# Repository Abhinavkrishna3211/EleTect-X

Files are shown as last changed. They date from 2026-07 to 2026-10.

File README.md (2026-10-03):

# EleTect X

**Adaptive Physical-AI platform for Human–Elephant Conflict (HEC) mitigation.**

EleTect X is a rugged, solar-powered, autonomous forest-edge node built on the Arduino UNO Q. It
detects elephants early through the ground (seismic), confirms with on-device vision, deters with
an adaptive, non-habituating light + sound response, alerts rangers and residents, and coordinates
with neighbouring nodes to steer wildlife safely — day and night, without cloud dependence in the
control loop.

## Why it's different

- **Seismic-primary, multimodal** detection (all-weather, day/night) — not a camera trap.
- **Adaptive deterrence** that measures outcomes and learns (contextual bandit), avoiding habituation.
- **Distributed coordination** — nodes create safe herding corridors, not random noise.
- **Ultra-low-power** event-driven architecture; weeks of autonomy on solar + LiFePO4.
- **Explainable fusion** — every alert traces back to which sensor said what, not a black box.
- **Extensible** — optional environmental / fire-risk / anti-poaching pods; road-signage integration.

## How it works

A node pairs an STM32U585 real-time microcontroller with a Qualcomm QRB2210 Linux computer on one
Arduino UNO Q board, split by responsibility rather than by chip:

```text
   Geophone / mic (always-on, µA)
            │
            ▼
   ┌────────────────────┐   footfall / acoustic events   ┌──────────────────────┐
   │  MCU — reflex       │ ───────────────────────────▶  │  MPU — cognition      │
   │  STM32U585          │  ◀───────────────────────────  │  QRB2210 (Linux)      │
   │  sensors, actuators,│      decisions (deter/alert)   │  vision, fusion,       │
   │  LoRa, power, safety│                                │  bandit, coordination  │
   └────────────────────┘                                └──────────────────────┘
            │                                                        │
            ▼                                                        ▼
   Horn + LED deterrence · IR illumination             LoRaWAN uplink → ranger dashboard
```

- **Reflex (MCU, always-on):** geophone STA/LTA trigger, acoustic gunshot/chainsaw gate, actuator
  timing, safety rule-gates, LoRa MAC, power management. Runs whether or not the MPU is awake.
- **Cognition (MPU, event-driven):** wakes on a reflex-layer event, runs an on-device vision
  detector, fuses every available sensor with a weighted log-odds model
  (`L = L_prior + Σ aᵢ wᵢ (ℓᵢ − ℓ₀ᵢ)`, explainable — missing sensors just drop out), then picks a
  deterrence action with a contextual bandit that never repeats the same tone and stops once the
  animal retreats, instead of blasting a fixed siren until it stops working. The 940 nm IR
  illuminator is deliberately outside that loop — it lights the scene so the camera can see after
  dark, and is invisible to the animal.
- **Coordination:** nodes share detections over LoRa so a herd is steered along a forest-side
  escape lane, not trapped toward a village.
- **Autonomy:** all control decisions are made on the node. The cloud side is monitoring and
  analytics for rangers and residents, never in the detect→deter loop.

## Repository layout

| Path | Contents |
| --- | --- |
| [`app-lab/`](app-lab/) | Arduino App Lab package (manifest + assets) — the deployable app |
| [`device/mcu/`](device/mcu/) | STM32U585 real-time reflex firmware (C/C++, PlatformIO) |
| [`device/mpu/`](device/mpu/) | QRB2210 (Debian) cognition: vision, fusion, bandit, comms (Python) |
| [`ml/`](ml/) | Seismic/acoustic/vision model training + evaluation (off-device) |
| [`hardware/`](hardware/) | PCB (KiCad), enclosure CAD, wiring, bill of materials |
| [`web/backend/`](web/backend/) | Supabase schema, row-level security, edge functions |
| [`web/ingest/`](web/ingest/) | ChirpStack MQTT → Supabase bridge |
| [`web/chirpstack/`](web/chirpstack/) | LoRaWAN network server stack (Docker Compose) — gateway to database |
| [`web/frontend/`](web/frontend/) | Ranger/resident dashboard + public site (React PWA) |
| [`docs/decisions/`](docs/decisions/) | Architecture decision records — the "why" behind every non-trivial call |
| [`docs/research/`](docs/research/) | Background research (behavioral science, platform, competitors) |
| [`docs/runbooks/`](docs/runbooks/), [`docs/specs/`](docs/specs/) | Field procedures and hardware bring-up specs |
| [`deployment/`](deployment/) | Field install scripts and service units |
| `scripts/`, `tests/` | Cross-cutting utilities and tests |

Each top-level module also has its own README with the detail specific to it —
[`device/README.md`](device/README.md), [`web/README.md`](web/README.md),
[`ml/README.md`](ml/README.md), [`hardware/README.md`](hardware/README.md).

## Getting started

### Run the app on real hardware

The fastest path to a working node is [`app-lab/eletect-x/`](app-lab/eletect-x/) — a real Arduino
App Lab package. In short:

```bash
cp device/mcu/src/secrets.h.example device/mcu/src/secrets.h   # fill in your LoRaWAN credentials
BOARD_HOST=<your-board>.local scripts/sync-to-board.sh
```

then build/run the `eletect-x` app from App Lab or `arduino-app-cli`. See
[`app-lab/eletect-x/README.md`](app-lab/eletect-x/README.md) for the full sequence and
prerequisites.

### Build and test each piece independently

| Module | Command | Notes |
| --- | --- | --- |
| `device/mcu` | `pio run -e native` / `pio test -e native` | Host-only compile/test harness; never produces a flashable image ([details](device/mcu/README.md)) |
| `device/mpu` | `ruff check .` / `pytest -q` | Host-only lint/test; the real Bridge runtime only exists on the board ([details](device/mpu/README.md)) |
| `ml/` | see [`ml/README.md`](ml/README.md) | Training pipelines, run on a PC |
| `web/frontend` | `npm run dev` / `npm run build` | React PWA — dashboard + public site |
| `web/backend` | see [`web/backend/README.md`](web/backend/README.md) | Supabase schema + edge functions |
| `web/ingest` | `npm test` / `npm run build` | MQTT → Supabase bridge ([details](web/ingest/README.md)) |
| `web/chirpstack` | `docker compose up -d` | LoRaWAN network server; needs Docker ([details](web/chirpstack/README.md)) |

### Inspect the trained models

Both on-device models are public on Edge Impulse — impulse, DSP block, training data, and the test
results they were accepted on, exactly as they run on a node:

| Model | Project | What it does |
| --- | --- | --- |
| Acoustic — `ETX-A` | [studio.edgeimpulse.com/public/1110036/live](https://studio.edgeimpulse.com/public/1110036/live) | PANNs Cnn10 transfer over a custom log-mel DSP block; `ambient` / `chainsaw` / `elephant_call` / `gunshot`, 92.6% over a 605-clip held-out split |
| Vision — `ETX-V` | [studio.edgeimpulse.com/public/1097972/live](https://studio.edgeimpulse.com/public/1097972/live) | YOLO-Pro object detector, 160 px int8 — detects `Elephant`, `Boar` and `Fox`, trained against a fourth `Background` class of negatives; confirms a reflex-layer trigger before any deterrence fires |

The training and evaluation pipelines that produced them, the per-sample dataset manifests, and the
caveats worth reading before quoting either number are in [`ml/acoustic/`](ml/acoustic/) and
[`ml/vision/`](ml/vision/).

### Understand a design decision

Every non-trivial engineering call — why seismic over camera-only, why this horn, why this fusion
math — is recorded as an ADR in [`docs/decisions/`](docs/decisions/), numbered in the order they
were made. Start with
[`0001-physical-ai-sensing-and-fusion-architecture.md`](docs/decisions/0001-physical-ai-sensing-and-fusion-architecture.md)
for the core sensing/vision/fusion architecture.

## Status

**Field testing.** The build is complete — reflex firmware, cognition layers, the LoRaWAN path and
the web app — and nodes are deployed in two areas, running the full detect → confirm → deter loop on
real hardware at the forest edge. The uplink path is live end to end: node → gateway → ChirpStack →
bridge → Supabase → dashboard.

## License

MIT — see [`LICENSE`](LICENSE).

The deterrence audio on the device is third-party work under separate terms. Three of the
five tracks are CC-BY and require attribution wherever this is distributed; the credits are
in [`docs/AUDIO_CREDITS.md`](docs/AUDIO_CREDITS.md) and travel with any build or write-up
that ships the sounds.

The training corpora are third-party work too, and the MIT licence above does not cover them. The
vision set is CC BY 4.0 and CDLA-Permissive, which require attribution; per-source terms are in
[`ml/vision/dataset_manifest.json`](ml/vision/dataset_manifest.json) and the table in
[`ml/vision/README.md`](ml/vision/README.md). The acoustic set is mixed and is tracked per sample in
[`ml/acoustic/dataset_manifest.json`](ml/acoustic/dataset_manifest.json). Check both before reusing
the data; the models themselves carry no such restriction.

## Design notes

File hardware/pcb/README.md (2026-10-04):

# Schematics

`eletect_x/` is the KiCad project for the field board: four sheets (geophone, LED and IR, sound and
LoRa, power) under one root sheet, with the same Arduino UNO Q drawn on each. `eletect_x_schematics.pdf`
is the full export and `erc_report.txt` the last ERC run.

The sheets and the field board are the same design. There are no known differences to track.

Pins used on the UNO Q match `device/mcu/src/config.h`:

| Sheet | Pins |
|---|---|
| Geophone | A4/PC1 SDA, A5/PC0 SCL (I2C3, `Wire2`) |
| LED and IR | D3/PB0 left wing, D6/PB1 right wing, D7/PB2 IR board |
| Sound and LoRa | D0/PB7 RX, D1/PB6 TX, D4/PA12 select, D11/PB15 amp enable |

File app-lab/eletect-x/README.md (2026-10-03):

# EleTect-X — App Lab package

This folder is the deployable Arduino App Lab package for the real EleTect-X app —
the thing that actually runs on the UNO Q. It is **not** a copy of the source: the
MCU sketch lives in [`device/mcu/src/`](../../device/mcu/) and the MPU program lives
in [`device/mpu/`](../../device/mpu/); those two directories are the single source of
truth and have their own build/test tooling (PlatformIO, `ruff`/`pytest`). This folder
holds only what an App Lab app needs that isn't part of either source tree — the
manifest and any bundled assets — plus the one-command script that assembles the two
into a real app on your board.

## Layout

```text
app-lab/eletect-x/
  app.yaml     App Lab manifest (name, icon, ports, bricks)
  assets/      Static assets bundled with the app (currently empty)
  README.md    this file
```

At deploy time, `scripts/sync-to-board.sh` fills in the two directories App Lab
expects alongside `app.yaml` — `sketch/` from `device/mcu/src/` and `python/` from
`device/mpu/` — directly on the board. They are not created or committed here, so
there is exactly one place to edit MCU or MPU code, never two copies to keep in sync.

## Deploying — the fast path

1. Install [App Lab](https://docs.arduino.cc/software/app-lab/) and complete its
   First Setup wizard against your UNO Q at least once, so the board has Wi-Fi,
   SSH, and `arduino-app-cli` set up.
2. Copy `device/mcu/src/secrets.h.example` to `device/mcu/src/secrets.h` and fill in
   your own LoRaWAN OTAA credentials.
3. Put the vision checkpoint in place. Model binaries are not versioned in this
   repo, so `device/mpu/models/vision/` is empty in a fresh clone and the sync
   script aborts until you fill it. Export the deployed build —
   `runF_res160_noattnrelu_int8.eim`, YOLO-Pro 160 px int8 — from Edge Impulse
   project [1097972](https://studio.edgeimpulse.com/public/1097972/live) as a Linux
   (AARCH64) `.eim` and drop it there. [`ml/vision/README.md`](../../ml/vision/README.md)
   records the exact build and its `sha256` so you can confirm you have the right bytes.
4. From the repo root, with the board reachable over SSH:

   ```bash
   BOARD_HOST=<your-board>.local scripts/sync-to-board.sh
   ```

   This pushes `app.yaml` and `assets/` from this folder, the MCU sketch, the MPU
   program and the vision checkpoint into `~/ArduinoApps/eletect-x/` on the board,
   creating the app if it doesn't exist yet.
5. Install the vision runner, once per board:

   ```bash
   BOARD_HOST=<your-board>.local deployment/install/install-vision-runner.sh
   ```

   The Edge Impulse runner has to run host-side as the `arduino` user rather than
   inside the App Lab container — the container is on a bridge network and cannot
   reach the host's `127.0.0.1:1337`. The unit this installs loads the checkpoint
   synced in step 4 and serves inference on port 1337; the MPU program is a client
   of it.
6. Open App Lab (or `arduino-app-cli`) and build/run the `eletect-x` app like any
   other App Lab project.

See [`device/mcu/README.md`](../../device/mcu/README.md) and
[`device/mpu/README.md`](../../device/mpu/README.md) for what each side actually
does, and the root [`README.md`](../../README.md) for the full project layout.

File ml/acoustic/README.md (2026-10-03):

# Acoustic classifier — four-class model, trained on real public + field-captured data

> **Looking for the walkthrough?** [`TUTORIAL.md`](TUTORIAL.md) is the step-by-step version —
> empty Edge Impulse project through to a model registered on the board, written for someone
> reproducing this from scratch. This file is the working record: what was tried, what was
> measured, and what was rejected. The tutorial is narrative; this is evidence.

## Which Edge Impulse project is production

**Production is project 1110036 (`ETX-A`), impulse 19, deploy v7** — the PANNs Cnn10 transfer
model. Enterprise account; project ID only is recorded here, the API key is not in the repo and
must be supplied through `EI_API_KEY` at run time.

The history is worth stating once, because two projects appear all over this file and **their
names were swapped in Studio on 2026-10-03**: 1110036 was `ETX-Test` and is now `ETX-A`, while
1109511 was `ETX-A` and is now `ETX-A-test`. Text written before that date — here, in the ADRs and
in captured console output — still uses the old names. **Go by project ID, never by name.**

**1109511 (`ETX-A-test`; `ETX-A` before the rename)** was built on 2026-09-23 to *be* production: a clean rebuild from the frozen
group-aware split, deliberately kept off the experiment path so its history stayed clean. It did
not reach the bar. Its best MFE configuration missed the 80%-per-class target on every class, and
`chainsaw` sat in the high single digits to mid-twenties across six separate real training runs on
the identical post-audit dataset (four MFE, two MFCC) — see the 2026-09-22 and 2026-09-15 Result
sections below, and `ACOUSTIC_MODEL_REPORT.md` for why.

**1110036 (`ETX-A`; `ETX-Test` before the rename)** started as the scratch project for
architecture/data/DSP/window sweeps.
The PANNs Cnn10 transfer impulse built there cleared the bar that 1109511 never did:

| | 1110036 impulse 19 |
|---|---|
| overall, 605 held-out clips | **92.6%** |
| ambient | 92.8% recall / 92.8% precision |
| chainsaw | 91.2% recall / 89.9% precision |
| elephant_call | 93.1% recall / 91.5% precision |
| gunshot | 92.6% recall / 93.4% precision |

So the roles swapped: the scratch project carries the model that works, and it is what ships. See
[ADR 0032](../../docs/decisions/0032-acoustic-production-project-is-1110036.md).

**The comparison is like-for-like, not a leakage artefact.** That is the first thing to check when
a scratch project outscores a carefully-built one by thirty points, and it was checked. 1110036 was
re-uploaded from the same frozen split: all 4,293 clips pushed with label **and** train/test
category driven by `harness/split.json` rather than by Studio's own 80/20, verified by API as an
exact filename-and-label match (training 3,688 / testing 605, 0 missing, 0 extra), and re-verified
against `ei_upload_ledger.json` at scoring time (605/605). The 92.6% above is measured over the
same 605 test clips the harness uses, so it is directly comparable to every other number in this
file. Full numbers: `harness/results_eim_impulse19.json`.

**Naming hazard — fixed in Studio, but inverted in older text.** The 2026-10-03 rename removed the
original hazard: production (1110036) is now `ETX-A` and the dormant project (1109511) is
`ETX-A-test`. The remaining risk runs the other way. Anything written before that date calls
1110036 `ETX-Test` and 1109511 `ETX-A`, so a reader going by name could look at `ETX-A` in Studio,
believe the older docs when they call `ETX-A` the abandoned MFE project, and reset production.
Act on the project ID.

(An earlier project, 1094275, was abandoned before any of this work and is never referenced again
in this document or in either script.)

**Status: trained, with real held-out numbers.** The numbers in the Result sections below are
copied verbatim from `edge_impulse_train_acoustic.py`'s `report_results()` output for each run —
nothing in this document is estimated, rounded from a different run, or averaged across classes.

Most of those sections predate the PANNs model and describe 1109511's MFE/MFCC lineage. They are
kept because they are the evidence for why that lineage was abandoned, **not** because they
describe what ships. In particular, the 2026-09-22 "Result — MFE vs MFCC x `autoClassWeights` on
the current dataset" section is 1109511's final trained state (Run E), and each of its four runs
left 1109511's live impulse in whatever state that run produced — Run E was a deliberate rebuild
back to the best-known config so the project was not left worse. That is now history: 1109511 is
not the deployed model and its numbers must not be quoted as production.

## Class scheme, and why it is four classes, not seven

The wire scheme is:

```
gunshot, chainsaw, elephant_call, ambient
```

`elephant_call` is the only one of these that feeds the deterrence (bandit) fusion decision
in `device/mpu/services/reflex_loop.py`; the rest are alert/detection-only. See
`docs/decisions/0024-acoustic-species-classification-deferred.md` and its same-day amendment
for the routing decision this model plugs into (Track B, a separate deferred change — this
document covers only the model).

### `boar_call` and `predator_call` were sourced, trained, and dropped

The amendment that authorized this work originally scoped **seven** classes, adding
`boar_call` and `predator_call` (lion + leopard + tiger lumped) to the five above. Both were
actually sourced (Freesound multi-query pulls, ESC-50 "pig" for boar, xeno-canto `Panthera`
and BBC Sound Effects for predator) and trained through the complete exploration described
below — data rebalancing, an `autoClassWeights` on/off A/B, a DSP A/B, an EON Tuner wide
search, a transfer-learning attempt, and the full `{3,4,6,8,10}` s window-length sweep. In
every one of those configurations, both classes stayed at or near the seven-class chance
floor (1/7 = 14.3%):

| window | `boar_call` recall | `predator_call` recall |
|---|--:|--:|
| 3.0 s | 2.6% | 10.7% |
| 4.0 s | 0.0% | 0.0% |
| 6.0 s | not trained — fell below the 150-clip data floor at this window length | 0.0% (n=3, test set collapsed) |
| 8.0 s | 0.0% | 0.0% |
| 10.0 s | 5.3% | 0.0% |

The EON Tuner's own best trial scored `boar_call` 18.4% and `predator_call` 0.0% across a
70-trial-budget search that explored MFE/MFCC/spectrogram DSP crossed with conv1d/conv2d
architectures — the platform's own automated search did no better. `autoClassWeights: True`
did lift both above chance on one dataset configuration (`boar_call` to 18.4%,
`predator_call` to 28.6%), but only by costing the two highest-stakes classes real recall
(`elephant_call` −16.5 points, `gunshot` −10.5 points) — see the `autoClassWeights` section
below for the full trade-off.

Per the explicit, pre-agreed fallback ("if boar and predator are working
very low, drop it after all possible fixes are explored"), both classes are **dropped from
the wire scheme entirely** — not folded into `ambient`, since `ambient` means background/
silence, not a mislabeled animal call, and folding would corrupt that class's meaning. The
device-side `AcousticClass` enum change this implies is a separate, deferred Track B edit;
this document and the two acoustic scripts are the only places the drop is applied. Every
fetcher, query table, and floor-handling special case for these two classes has been removed
from `scripts/edge_impulse_upload_acoustic.py` and `scripts/edge_impulse_train_acoustic.py`
rather than left in as dead code.

`boar_call`'s weak showing tracks a genuine data ceiling, not a code gap: its 12-query
Freesound search (`"wild boar"`, `"boar grunt"`, `"wild pig squeal"`, ...) against a 600-clip
cap only ever found 157 unique clips, plus 40 from ESC-50's "pig" category — 197 total,
nowhere near the other classes' final counts. `predator_call` never cleared the 150-clip
floor at all in the final configuration. xeno-canto was a hoped-for supplement for both but
returned zero clips — its v2 API is retired and v3 requires an account key this project does
not hold (confirmed live, not assumed).

### `vehicle` was retrained with real field data, then dropped (2026-09-14)

`vehicle` was part of the wire scheme from the start of this document and had its own
Freesound data widened on 2026-09-13 alongside `chainsaw` (see "Reading these numbers
honestly" below, in the pre-drop Result section this document used to lead with). At that
point `vehicle` looked like a genuine success story — held-out recall had jumped from 27.7%
to 55.6% — while `chainsaw` improved only modestly and the writeup at the time already
flagged, in prose, that "these two classes' Freesound-sourced audio — both sustained
mechanical/engine drones — sit close together in MFE feature space at this window length."

On 2026-09-14, 15 new real `chainsaw` clips and 10 new real `elephant_call` clips (laptop/
phone recordings, not Freesound) were added and the model retrained. `chainsaw` held-out
recall did not just fail to improve — it **collapsed to 0.0% (0/79)**. The training job's own
validation-time confusion matrix (not just the held-out split, which could in principle have
been an unlucky test draw) showed the same collapse during training: `chainsaw` recall was
1.7% (1/60) at validation time, with 33 of 60 `chainsaw` validation clips predicted `vehicle`.
Seeing the identical failure in both the training-time validation split and the independent
held-out test split is what confirmed this was a genuine, systematic class-boundary collision
between `chainsaw` and `vehicle` — not noise from one bad split. The new real clips did not
create this weakness; they pushed an already-documented latent one (see the prose warning
above, written the day before) into outright collapse. The bulk of both classes' data was,
and remained, Freesound-sourced sustained-engine-drone audio; the ~25 new laptop/phone clips
were a small fraction of either class's total.

Given the field-build deadline driving this work, the decision was to **drop `vehicle`
from the wire scheme rather than continue diagnosing the collision** — not fold it into
`ambient`, for the same reason `boar_call`/`predator_call` were not folded into `ambient`
above (`ambient` means background/silence, not a mislabeled vehicle). Dropping `vehicle` and
retraining recovered `chainsaw` to **55.7% (44/79) — its best score in this project's
history** (see the current Result section below for the full four-class numbers). All 517
`vehicle`-labeled samples (415 training + 102 testing) were deleted from Edge Impulse project
1109511 via the Studio API; the raw audio itself stays cached under
`ml/datasets/acoustic/raw/` (gitignored), so `vehicle` can be re-uploaded from cache without
re-fetching if the class is ever revived with a plan to actually separate it from `chainsaw`
(a different DSP/window, or audio sourced from something other than Freesound engine-drone
recordings). As with the boar/predator drop, every fetcher, query table, and constant
specific to `vehicle` has been removed from `scripts/edge_impulse_upload_acoustic.py` rather
than left in as dead code; `scripts/edge_impulse_train_acoustic.py` needed no functional
change since it already reads expected classes from the manifest rather than hard-coding
them.

## Dataset — the frozen split, as uploaded to project 1109511

> The dataset described here is the corpus both projects are trained and scored on. The
> *project* named below is 1109511, because this section was written when 1109511 was the
> designated production project; the same 3,688/605 split was later re-uploaded to 1110036
> by filename, which is what makes the two projects comparable. See ADR 0032.

Manifest schema `eletect-x/acoustic-clip-manifest/3`, `ml/acoustic/dataset_manifest.json`
(committed; records source, license, and sha256 for every clip the manifest currently
tracks — see the test-bucket note below for a case where this undercounts what is actually
in the project). Real counts, from that manifest, **after the 2026-09-15 chainsaw
data-quality audit and ambient-cap pullback** (see the two subsections immediately below —
this supersedes the 2026-09-14 all-four-classes-widening counts quoted in an earlier revision
of this table; see git history if those are needed):

| Class | Total | Train | Test | Primary sources (license as recorded per clip) |
|---|--:|--:|--:|---|
| `gunshot` | 577 | 382 | 195 | Mendeley `x48cwz364j` v3 + Freesound 19-query supplement, mostly CC0/CC BY |
| `ambient` | 762 | 610 | 152 | Mendeley `x48cwz364j` v3 background folder + ESC-50 nature categories (crickets/insects/chirping_birds/wind/frog/rain, CC BY-NC 3.0) + Freesound 11-query forest/jungle-ambience supplement |
| `chainsaw` | 227 | 178 | 49 | ESC-50 ESC-10 subset (CC BY) + Freesound 19-query supplement (`"power saw"` dropped 2026-09-15 — see below), mostly CC0 |
| `elephant_call` | 382 | 303 | 79 | `github.com/HiruDewmi/Audio-Classification-for-Elephant-Sounds` (**no license** — see Caveats) + Freesound 18-query supplement, mostly CC0/CC BY |

This table reports `dataset_manifest.json`'s own per-class counts, which — per the
"manifest is a floor, not the real count" note below — undercount what the live project
actually holds: the training runs in the Result section below report **1,775 training / 552
testing** clips read from project 1109511 at train time, larger than this table's 1,341/475
sum for the same reason documented since the first time this gap was noticed (the resumable
upload ledger accumulates clips across every historical run's differently-seeded sample; the
manifest keeps only the latest run's own selection). Field-captured XIAO and laptop/phone
clips from earlier revisions of this table are still present in the raw cache and in earlier
uploaded batches and contribute to that live-project total even though they no longer appear
in the manifest's latest per-class breakdown above. `vehicle` (dropped 2026-09-14, see the
class-scheme section above) stays out of the wire scheme. Every class clears the project's
own data floor (`CLIP_FLOOR = 150`) and is tagged `floor_status: trained` in the manifest.

**Superseded as of 2026-09-23: the live project now holds 3,688 training / 605 testing
clips.** The 1,775/552 figures below are accurate for the runs that recorded them and are
left as written, but they are no longer the current size of project 1109511. Every number in
the 2026-09-23 investigation is on the 3,688/605 data, and the 605 testing clips are the
canonical held-out set that all comparisons are scored against.

### Chainsaw data-quality audit — the `"power saw"` query dropped (2026-09-15)

The 2026-09-14 all-four-classes widening's own writeup (see the Result section below it, and
Caveat 5) flagged the `"power saw"` Freesound query — which alone contributed 138 of
`chainsaw`'s 321 Freesound clips at the time — as the leading, but unverified, suspect for
that widening's `chainsaw` collapse (55.7%→18.8%/13.9%). That audit was carried out: all 136
clips the query pulled were listened to. The finding is not what was guessed — the query does
not mostly return other power tools (circular saws, angle grinders); it mostly returns two
kinds of genuinely off-target audio that share the query term's ambiguity: synthesizer
"sawtooth waveform" demos (the tool/waveform sense of "saw") and generic factory/mechanical-
impact sound-effects-pack content, both cases where "power saw" over-matched Freesound's tag
search rather than the class label matching real chainsaw audio. `"power saw"` was removed
from `FREESOUND_QUERIES["chainsaw"]` and the remaining chainsaw query list widened from 13 to
19 real chainsaw-specific queries (`"chainsaw cutting wood"`, `"logging chainsaw"`, `"Stihl
chainsaw"`, `"Husqvarna chainsaw"`, `"motosierra"`, `"tronconneuse"`, and others) to replace
the lost volume with on-target audio instead. This is a genuine, verified data-quality fix,
not a guess carried forward unverified — see the Result section below for whether it actually
recovered `chainsaw`'s recall (it did not, cleanly — read that section before assuming this
fix worked).

### Ambient-cap pullback (2026-09-15)

The same all-four-classes widening grew `ambient` to 700 total clips specifically to test
whether more ambient volume would help (it did, but only under `autoClassWeights: False` —
see that Result section's honest read). Separately, `AMBIENT_CAP` had briefly been pushed
further, to 700 within the upload script's own per-run cap (not merely the manifest's `700`
row above), which combined with the ESC-50 nature supplement and the XIAO field clips to push
`ambient`'s live TRAIN split to roughly 750 — about 5x the thinnest trained class — at which
point, with `autoClassWeights` off, the model answered `ambient` for nearly every clip
regardless of true label. `AMBIENT_CAP` was pulled back to 200 (keeping the ESC-50 nature
supplement — genuinely different recording rigs — in full, cutting only the redundant
single-rig Mendeley share) so `ambient`'s volume advantage stays within roughly 2x the
trained species classes rather than 5x. A large negative class is still deliberately kept
as the main defence against a false-positive storm in the field; it just cannot be allowed to
dominate the softmax outright.

### `elephant_call` Freesound query widened 3→12, then retrained (2026-09-14)

After the `vehicle` drop retrain (below) showed `elephant_call` as the model's weakest class
at 37.0% held-out recall, `FREESOUND_QUERIES["elephant_call"]` in
`scripts/edge_impulse_upload_acoustic.py` was widened from 3 queries to 12 ("elephant rumble",
"elephant trumpet", "elephant call", "elephant roar", "elephant bellow", "elephant
vocalization", "elephant growl", "elephant scream", "wild elephant sound", "elephant herd",
"baby elephant", "elephant infrasound"). Real yield, per query, from a live Freesound search:
"elephant trumpet" (28 hits), "elephant roar" (11), "elephant growl" (9), "elephant scream"
(9), "elephant call" (6), "elephant rumble" (2), "elephant vocalization" (2), "wild elephant
sound" (3), "elephant bellow" (1); "elephant herd", "baby elephant", and "elephant infrasound"
returned 0 hits each. After deduping against the clips the original 3-query pull had already
found, this added **16 net-new clips** (49 unique Freesound clips total vs. 33 before) —
`elephant_call`'s total went from 394 to 410 (313→326 train, 81→84 test). xeno-canto still
contributes 0 clips (`gen:Elephas`, API v3 needs an account key that is not set). The retrain
against this larger pool did raise `elephant_call`'s held-out recall substantially (see the
Result section below), but total model accuracy barely moved and the gain traces mostly to
`ambient` and `chainsaw` losing votes to `elephant_call` rather than to a cleaner decision
boundary — read that section's honesty subsection before treating this as a fix.

### Why the manifest's per-class test count is a floor, not the real count

Because the resumable `uploaded.json` ledger only *adds* newly-selected clips and never
removes one a later run's reseeded sample no longer includes, a class's real EI-side train/
test bucket is the union of every historical run's selection, while the manifest only records
the *latest* run's sample. This has shown up repeatedly across this project's history at
varying scale — a 14-training/1-testing-clip gap before the 2026-09-13 chainsaw/vehicle
widening, a 10/32-clip gap for chainsaw/vehicle after it, a 1,487/476-vs-1,341/436 gap after
the 2026-09-14 `elephant_call` widening — and shows up again, largest yet, after the
2026-09-15 chainsaw audit and ambient-cap pullback: every training run in the current final
Result section below reports Edge Impulse reading **1,775 training / 552 testing** clips from
project 1109511, versus this section's own 1,341/475 manifest sum — a 434/117-clip gap. The
manifest's per-class counts are real and verified (they are exactly what the most recent
upload run selected and recorded), they simply undercount what the live project actually holds
after several historical runs' worth of accumulated clips. The Result sections below report
each `classify` job's own real per-class counts (which do match that run's own training-log
testing total), not the manifest's, since that is what the model was actually tested against.

### Normalization (all sources)

- **8000 Hz mono** — matches the INMP441 target rate and Mendeley's native rate (the lowest
  of all sources), so every other source is downsampled, never upsampled. Resampling uses
  `scipy.signal.resample_poly` (anti-aliased), not stdlib `audioop.ratecv` — `ratecv` has no
  real anti-alias filter, and decimating 44.1 kHz Freesound/ESC-50 audio at roughly 5.5:1
  without one folds high-frequency energy back down into exactly the low mel bands the MFE
  DSP block reads.
- **10.0 seconds per clip**, centre-cropped or zero-padded — the window-length sweep's
  winner; see that section below for why.
- XIAO ESP32S3 Sense field captures get an additional DC-offset removal step (the onboard
  PDM MEMS mic's raw output carries a DC bias that a plain resample does not fix).

## Impulse (locked configuration)

- **Input** (block 1): time-series, 1 axis, 8000 Hz, **10000 ms window, 10000 ms increase**
  (no overlap — one window per clip, so no window spans two clips or mixes a class label
  with padded-in silence from a shorter source clip).
- **DSP** (block 2): **MFE** (mel-filterbank energy), 40 filters / 256-point FFT — Edge
  Impulse's stock 8 kHz default, and separately measured against MFCC (see DSP A/B below).
  Frame length stays at the block default (0.02 s); frame stride is widened from the 0.01 s
  default to **0.020835 s** for this window length only, because Edge Impulse hard-caps
  feature generation at 500 frames per window and the 10 s window would otherwise compute
  ~499 frames (598 was measured to actually fail at 6 s) — `frame_stride_for_window()` in
  the training script widens the stride by the minimum amount needed, and only for windows
  that need it (3 s and 4 s keep the untouched 0.01 s default). This trades temporal
  resolution for headroom under the platform cap; it is a documented, deliberate
  trade-off, not a hidden one.
- **Learn** (block 3): Keras classification, from-scratch 2-layer 1D CNN —
  `conv1d(16) -> conv1d(32) -> dense(24)`, kernel size 3, 120 training cycles, learning rate
  0.001, batch size 32, **`autoClassWeights: False`**, spectrogram augmentation off,
  `minimumConfidenceRating: 0.1`, INT8 profiling on (`profileInt8: True`, matching the
  QRB2210 A53 Linux MPU deployment target).

  The block also carries `dropoutRate: 0.25/0.25/0.4`, and **that setting does nothing.**
  Dumping the Keras script Edge Impulse actually generates from this visual config shows no
  `Dropout` layer anywhere in it; the value is accepted by the API, echoed back on read, and
  never reaches the model. Confirmed by training two marker-verified expert-mode scripts that
  differ only in the presence of three `Dropout` layers. So every visual-mode run recorded
  below trained an unregularised network, whatever its stored config claims.

  **What the inert setting costs depends on the head, and is smaller than it first looked.**
  On Edge Impulse's internal validation slice the two scripts scored 61.25% / 0.579 macro F1
  without dropout and 63.96% / 0.616 with, which looked like a real +2.7. That slice is drawn
  from the training pool and is not group-aware, so it flatters regularisation; it is not a
  test set and should not be quoted as one. Re-scored on the canonical 605-clip test set,
  dropout on the stock `Flatten` head is worth +0.5 to +1.3 points — real, because Edge
  Impulse's training is deterministic and run-to-run variance is exactly zero, but minor.

  Once the head is replaced with global average pooling the sign reverses: 70.9% without
  dropout against 69.4% with. A 768-parameter head is already constrained enough that
  0.25/0.25/0.4 over-regularises it. The inert setting is a genuine Edge Impulse defect and it
  invalidated three experiment arms, but it was never the main cost — the `Flatten` head was.
  See [ACOUSTIC_MODEL_REPORT.md](ACOUSTIC_MODEL_REPORT.md) for the full accounting.

Every one of those choices was measured, not assumed — see Exploration history below.

## Exploration history (what was tried, what won, and why)

All of this ran against **1110036**, which was the scratch project at the time and is now
production (see "Which Edge Impulse project is production" at the top). So this history is the
deployed project's own history — the sweeps below are not a parallel track that was thrown away,
they are how the shipping model was arrived at. Every step is reproducible via the `--dsp`,
`--learn`, and `--clip-seconds` flags on `edge_impulse_train_acoustic.py`.

### Architecture search — closed, data-limited not capacity-limited

Three points were measured on the same (pre-final) dataset at a 4.0 s window:

| Architecture | Cycles | Held-out |
|---|--:|--:|
| 4-conv stack, dense-64 head, heavy spectrogram augmentation | — | ~26% argmax (near-random) — this was an earlier over-parameterized attempt that collapsed the majority class |
| 2-conv (16→32) + dense-24 | 120 | 46.4% (252/543) |
| 3-conv (24→48→64) + dense-32 | 250 | 45.2% (252/558) |

The larger net, wider head, and 2x training cycles bought nothing — the two curves sit on
top of each other and the train/held-out gap stayed ~4–5 points either way. That is a data
ceiling, not a capacity ceiling, so the smaller net was kept: identical accuracy, fewer INT8
parameters to profile and deploy. Architecture search closed here; every subsequent gain
came from the data, not the model.

### Data rebalancing — three iterations, real regressions along the way

Reported honestly because two of the three iterations were **regressions**, not just steps
toward the final config:

1. **Freesound gunshot supplement, no rebalancing** — added a 10-query Freesound pull for
   `gunshot` (Mendeley's own gunshot and ambient clips share one recording rig, so the model
   was keying on the rig's signature rather than the sound). Held-out total fell to 43.5%
   (269/618) — `gunshot` recall improved (+7 points) but `boar_call` and `chainsaw` collapsed
   to 2.6% and 4.4% because the uncapped `ambient` (940 clips) and `gunshot` (830 clips)
   swamped the thinner classes.
2. **Rebalance + XIAO field data folded in** (`GUNSHOT_TRAIN_CAP` 380→200,
   `FREESOUND_CAP["gunshot"]` 300→130, `AMBIENT_CAP` 700→200) — held-out total 41.3%
   (217/525), still below the original 46.4% baseline, but `elephant_call` jumped to 63.3%
   (real XIAO elephant-noise data helping directly) and `chainsaw`/`gunshot`/`vehicle` all
   improved. `boar_call` (2.6%) and `predator_call` (3.6%) stayed collapsed — this triggered
   the `autoClassWeights` A/B below.
3. This rebalanced-plus-XIAO configuration (with `autoClassWeights` locked `False`, see
   next section) is what carried forward into the DSP A/B, EON Tuner, transfer-learning
   attempt, and window sweep.

### `autoClassWeights` — measured both ways, locked OFF

Same uploaded data, same DSP/architecture, retrain-only comparison:

| Class | Weights OFF | Weights ON | Delta |
|---|--:|--:|--:|
| `elephant_call` | 63.3% | 46.8% | −16.5 |
| `gunshot` | 55.8% | 45.3% | −10.5 |
| `chainsaw` | 29.4% | 25.5% | −3.9 |
| `vehicle` | 38.3% | 36.2% | −2.1 |
| `ambient` | 30.7% | 29.7% | −1.0 |
| `boar_call` | 2.6% | 18.4% | +15.8 |
| `predator_call` | 3.6% | 28.6% | +25.0 |
| Total (micro) | 41.3% | 37.0% | −4.3 |

Turning class weighting on does lift `boar_call`/`predator_call` above the seven-class
chance floor — a real signal — but at the cost of the two highest-priority classes in the
deployed product: `gunshot` (P1 anti-poaching alert) loses 10.5 points and `elephant_call`
(alert **and** the sole acoustic input to the deterrence fusion decision) loses 16.5 points.
Weighted by the same elephant_call/gunshot/chainsaw priority average used for every other
decision in this document: 49.5% (weights off) vs. 39.2% (weights on). **Locked:
`autoClassWeights: False`.**

### DSP A/B — MFE vs MFCC, MFE wins decisively

`--dsp {mfe,mfcc}` on the identical rebalanced+XIAO dataset:

| Class | MFCC recall | MFE recall (locked) |
|---|--:|--:|
| `ambient` | 88.1% | 30.7% |
| `boar_call` | 0.0% | 2.6% |
| `chainsaw` | 11.8% | 29.4% |
| `elephant_call` | 55.7% | 63.3% |
| `gunshot` | 5.5% | 55.8% |
| `predator_call` | 0.0% | 3.6% |
| `vehicle` | 0.0% | 38.3% |
| **Total** | 28.4% (149/525) | 41.3% (217/525) |

Tie-breaker (elephant_call/gunshot/chainsaw weighted average): **MFCC 24.3% vs. MFE
49.5%** — more than 2x worse. The confusion matrix shows why: 164 of 181 `gunshot` clips
were predicted `ambient` under MFCC, which is also why `ambient`'s own recall looks inflated
(88.1%) — MFCC's cepstral truncation throws away exactly the transient/broadband energy
that separates a gunshot's percussive burst from background noise, which MFE's full
mel-band energy profile retains. This is expected: MFCC is a speech-tuned representation
(built to emphasize the smooth spectral-envelope shape that separates phonemes), applied
here to non-speech transient/impulsive sounds it was never designed for. **`--dsp` stays
defaulted to `mfe`.** Spectrogram was deliberately not added as a third variant — its
output bin count is not verified against the live API, and a wrong reshape-columns guess
risks a crash or silent misconfiguration for a block already expected to lose to MFE.

This comparison predates the chainsaw-audit/ambient-pullback dataset (project 1109511's current
1,775/552 4-class data) and was not re-verified against it until 2026-09-22 — see "Result — MFE
vs MFCC x `autoClassWeights` on the current dataset" below, which reconfirms the same verdict.

### EON Tuner — wide search, did not beat the hand-tuned config

Ran Edge Impulse's EON Tuner via its Enterprise API (`searchSpaceTemplate: audio_event`,
`targetDevice: arduino-unoq`, up to 70 trials across MFE/MFCC/spectrogram DSP crossed with
conv1d/conv2d architectures, INT8 optimization, 500 ms target latency). The search stopped
after 16 trials (the platform's own optimizer decided that was enough before entering full
optimization rounds). Best trial (`mfe-conv1d-934`): priority average 33.5%
(gunshot 52.5%, chainsaw 0.0%, vehicle 0.0%, elephant_call 48.1%, boar_call 18.4%,
predator_call 0.0%, ambient 8.9%) — well below the locked hand-tuned net's 49.5%. `chainsaw`
and `predator_call` scored exactly 0% in nearly every trial across the whole search space.
**Verdict: nothing to reproduce by hand — the locked from-scratch 2-conv net beat Edge
Impulse's own automated search.**

### EON Tuner — re-run on the current 4-class scheme (2026-09-15), still did not beat hand-tuning

The EON Tuner search above predates the `vehicle`/`boar_call`/`predator_call` drops and the
chainsaw data-quality audit, so it was re-run against project 1109511's current 4-class,
post-audit dataset (job `53782394`, `searchSpaceTemplate: audio_event`, `targetDevice:
arduino-unoq`) to check whether the narrower class scheme changed the conclusion. The search
ran 69.7 minutes and completed 10 trials, 5 of which returned metrics before the run stopped
itself. Best completed trial: int8 accuracy 56.52% (312/552 total), with `ambient` 52.6%,
`chainsaw` 2.1%, `elephant_call` 57.9%, `gunshot` 67.8%. This total is close to the range the
hand-tuned config's own runs land in (see the Result section below), but **the tuner's
`chainsaw` recall (2.1%) is far worse than any hand-tuned run achieves** — because, as
established in the earlier EON Tuner section above, **the tuner's search space varies only
the DSP block and the Keras architecture; it never varies `autoClassWeights`**, and every
trial in this run landed on the weights-off configuration this project already knows collapses
`chainsaw`. No trial was promoted with `set-tuner-primary-job` — nothing the tuner found beat
the manually-tuned, weights-on config on the metric this project actually cares about
(per-class recall on the minority classes, not total accuracy). **Verdict unchanged from the
7-class-era run: the tuner is not a substitute for hand-tuning `autoClassWeights` on this
dataset.**

### Transfer learning (`keras-transfer-kws`) — ruled out on a hard platform constraint

Attempted an A/B against all three confirmed-live pretrained KWS backbones
(`transfer_kws_mobilenetv1_a1_d100`, `transfer_kws_mobilenetv2_a35_d100`,
`transfer_kws_conv2d_tiny`; Syntiant NDP10x excluded — no hardware target for it). Every arm
was rejected identically: *"transfer learning for keyword spotting currently only works
with a window size of 1000ms"* — a hard, block-level Edge Impulse platform constraint, not
a per-backbone result. This project's window is far above 1000 ms because several classes
(a sustained chainsaw/engine whine, an elephant call, a running vehicle) need more than one
second of context to identify — they are not single-word "keyword" utterances the way KWS
transfer models assume. Forcing a 1 s window just to satisfy this block would have confounded
the comparison with an unrelated window-length change (1 s was never a window-sweep
candidate). **Not worked around — ruled out.** `TRANSFER_REQUIRED_WINDOW_MS` in the training
script fails this path fast, before wasting a feature-generation job, if anyone tries it
again at an incompatible window.

### Window-length sweep — all five candidates, no averaging

`{3.0, 4.0, 6.0, 8.0, 10.0}` seconds, each a full wipe → upload → train cycle against scratch
1110036 on the locked rebalanced+XIAO data, MFE DSP, `autoClassWeights` off, 2-conv net.
Picked by the elephant_call/gunshot/chainsaw priority average (the three highest-stakes
classes), never by raw total accuracy, since sample counts are not comparable across
candidates (re-cropping at a different window length changes how many non-overlapping
windows fit inside each raw source clip, so a class's real test-set size shifts with the
window — this is reported as observed below, not smoothed over).

| Window | Total good/bad | `ambient` | `boar_call` | `chainsaw` | `elephant_call` | `gunshot` | `predator_call` | `vehicle` | priority avg* |
|---|---|--:|--:|--:|--:|--:|--:|--:|--:|
| 3.0 s | 201/298 | 43.6% | 2.6% | 62.7% | 25.3% | 61.3% | 10.7% | 12.8% | **49.77%** |
| 4.0 s | 200/259 | 44.6% | 0.0% | 23.5% | 63.3% | 60.0% | 0.0% | 0.0% (n=7) | 48.93% |
| 6.0 s | 203/175 | 67.3% | not trained (below floor at this window) | 0.0% (n=14) | 55.6% | 52.5% | 0.0% (n=3) | 0.0% (n=7) | 36.03%† |
| 8.0 s | 233/292 | 46.5% | 0.0% | 39.2% | 39.2% | 67.4% | 0.0% | 27.7% | 48.60% |
| 10.0 s | 235/290 | 32.7% | 5.3% | 19.6% | 69.6% | 63.5% | 0.0% | 42.6% | **50.90%** |

\* elephant_call/gunshot/chainsaw simple average.
† 6.0 s excluded from serious contention: its `chainsaw` recall is measured on only 14 test
clips (vs. 51 at 3/4/8/10 s) and `boar_call` did not train at all at this window length —
longer windows mean fewer non-overlapping crops fit inside `boar_call`'s short raw source
clips, so the upload script's own data-floor logic pulled it below the training floor
entirely. This is a genuine, structural finding (window length and per-class data volume are
not independent), not an artifact of the frame-stride fix, but it makes 6.0 s unreliable to
compare against the other four.

**10.0 s wins** — highest priority average (50.90%) among the four reliable candidates, and
by a wide margin the best `elephant_call` recall (69.6%) of any window, which matters more
than raw total accuracy given `elephant_call`'s dual role (alert + fusion input). 3.0 s,
4.0 s, and 8.0 s all sit within about two points of each other and of 10.0 s on the priority
metric — this was not a landslide win, but it was the real winner by the metric this project
committed to before running the sweep. **Locked into `CLIP_SECONDS` (upload script) and
`DEFAULT_CLIP_SECONDS` (train script): 10.0 s.**

`boar_call` and `predator_call` recall across the five candidates
(3/4/6/8/10 s: boar 2.6%/0%/n·a/0%/5.3%, predator 10.7%/0%/0%/0%/0%) is the data referenced
in the class-scheme section above — at or near the chance floor in every reliable
configuration, which is what triggered the drop decision.

> **The Edge Impulse result sections below (every `## Result` heading dated 2026-09-22 or earlier)
> are superseded and their accuracies are withdrawn.** They were measured on a
> file-level split of a corpus of near-duplicates, which trained and tested on the same source
> recordings. They are kept as a record of what was tried and why, not as evidence of how well
> anything works. For held-out numbers, read
> *[Result — recording-level evaluation and an AudioSet-pretrained backbone](#result--recording-level-evaluation-and-an-audioset-pretrained-backbone-2026-09-23)*
> and the Caveats section, which explain the three leaks and quantify each one.

## Result — current production run (2026-09-14, 4-class, `vehicle` dropped)

This supersedes the 5-class result below. Same locked configuration (10.0 s window, MFE DSP,
2-conv architecture, `autoClassWeights: False`), run against project 1109511 after `vehicle`
was removed from the wire scheme and its samples deleted (see the class-scheme section
above), with the 15 new `chainsaw` and 10 new `elephant_call` laptop/phone clips already
folded in.

**Training job** (job 53749224, from Edge Impulse's own training-time validation split, 295
clips: ambient 77 / chainsaw 67 / elephant_call 63 / gunshot 88):

| Variant | Loss | Accuracy |
|---|--:|--:|
| float32 | 1.1112 | 51.2% |
| int8 | 1.2008 | 52.2% |

Training-time validation confusion matrix (float32; rows = true, columns = predicted, order
ambient/chainsaw/elephant_call/gunshot):

| True \ Predicted | `ambient` | `chainsaw` | `elephant_call` | `gunshot` |
|---|--:|--:|--:|--:|
| `ambient` | 33 | 22 | 5 | 17 |
| `chainsaw` | 16 | 36 | 8 | 7 |
| `elephant_call` | 9 | 19 | 29 | 6 |
| `gunshot` | 19 | 12 | 4 | 53 |

**Held-out model test** (job 53749250 — a real `classify` job over the actual test split, 473
clips, never seen during training; `minimumConfidenceRating: 0.1`, true argmax accuracy):

| Class | Good/Total | Recall | `floor_status` |
|---|--:|--:|---|
| `gunshot` | 148/212 | **69.8%** | trained |
| `chainsaw` | 44/79 | **55.7%** | trained |
| `ambient` | 44/101 | **43.6%** | trained |
| `elephant_call` | 30/81 | **37.0%** | trained |

**Total: 266/473 correct = 56.2%** (four-class chance floor = 25%).

**Confusion matrix** (rows = true label, columns = predicted; `uncertain` was 0 for every row
at `minimumConfidenceRating: 0.1`):

| True \ Predicted | `ambient` | `chainsaw` | `elephant_call` | `gunshot` |
|---|--:|--:|--:|--:|
| `ambient` | 44 | 29 | 4 | 24 |
| `chainsaw` | 17 | 44 | 7 | 11 |
| `elephant_call` | 24 | 24 | 30 | 3 |
| `gunshot` | 46 | 9 | 9 | 148 |

Full interactive results: <https://studio.edgeimpulse.com/studio/1109511/testing>

### Reading these numbers honestly

**`chainsaw` recovered to its best score in this project's history** (55.7%, up from 23.7% in
the last fully-documented 5-class run below, and up from 0.0% in the intervening run that
triggered the `vehicle` drop — see the class-scheme section above). Its confusion is now
spread across `ambient` (17/79) and `gunshot` (11/79) rather than concentrated in one
dominant confusable class, consistent with the vehicle-collision diagnosis: removing the one
class it was colliding with let its own decision boundary separate from the others again.

**`gunshot` improved too** (69.8%, above every gunshot number previously recorded for any
5-class configuration in this document, which ranged 55.8%–64.1%) and its confusion pattern
is unchanged in kind — still mostly `ambient` (46/212).

**`elephant_call` and `ambient` both regressed, and this is not yet fully explained.**
`ambient` fell to 43.6%, below every previously recorded 5-class number (55.4%–63.4%).
`elephant_call` fell to 37.0% (30/81) — below the 50.6% recorded for the 2026-09-13 widening
run, and further below the roughly 58.0% recall it scored in the run immediately preceding
the `vehicle` drop (training job 53748973 / classify job 53749012 — the same run whose
training-validation confusion matrix supplied the 33/60 chainsaw-to-vehicle misroute evidence
above). Its confusion is now split almost evenly between `chainsaw` (24/81) and `ambient`
(24/81). Two explanations are both consistent with what has been measured, and **no repeat
run was made to distinguish them**, given the build deadline:

1. **A genuine side effect of removing `vehicle`.** With `vehicle` gone, the softmax has one
   fewer place to route a misclassification — probability mass that a 5-class model might
   have (correctly or incorrectly) assigned to `vehicle` is now redistributed only among the
   remaining three off-target classes, and `chainsaw`/`ambient` may simply have picked up more
   of `elephant_call`'s spillover than `vehicle` used to.
2. **Ordinary run-to-run variance.** This project has already documented single-toggle swings
   of this general size — `autoClassWeights` alone moved `elephant_call` by 16.5 points and
   `vehicle` by up to 27.9 points in earlier A/Bs (see below) — so a ~13-21 point swing across
   a retrain that changed both the class roster *and* the training data is not unprecedented,
   even though it is on the larger end of what has been seen.

Total accuracy (56.2%) is reported for completeness only, per this document's standing
convention; it is not the metric this project optimizes for. The honest summary for this run
is: `chainsaw` is fixed, `gunshot` is fine, and `elephant_call` — the one class that also
feeds the deterrence fusion decision — is now this model's weakest point and the open
question for future work, not `chainsaw`.

## Result — retrain after widening `elephant_call` sourcing (2026-09-14, supersedes the run above)

Same locked configuration and class roster as the run above, retrained against project
1109511 after the Freesound query widening described in the Dataset section (+16 net-new
`elephant_call` clips, 394→410 total).

**Training job** (job 53749573, from Edge Impulse's own training-time validation split, 298
clips: ambient 77 / chainsaw 66 / elephant_call 69 / gunshot 86):

| Variant | Loss | Accuracy |
|---|--:|--:|
| float32 | 1.0383 | 54.7% |
| int8 | 1.0381 | 55.4% |

**Held-out model test** (job 53749601 — a real `classify` job over the actual test split, 476
clips, never seen during training; `minimumConfidenceRating: 0.1`, true argmax accuracy):

| Class | Good/Total | Recall | Prior run (394-clip `elephant_call`) | `floor_status` |
|---|--:|--:|--:|---|
| `gunshot` | 143/212 | **67.5%** | 69.8% | trained |
| `chainsaw` | 37/79 | **46.8%** | 55.7% | trained |
| `ambient` | 28/101 | **27.7%** | 43.6% | trained |
| `elephant_call` | 59/84 | **70.2%** | 37.0% | trained |

**Total: 267/476 correct = 56.1%** (four-class chance floor = 25%) — essentially unchanged
from the prior run's 56.2%.

**Confusion matrix** (rows = true label, columns = predicted; `uncertain` was 0 for every row):

| True \ Predicted | `ambient` | `chainsaw` | `elephant_call` | `gunshot` |
|---|--:|--:|--:|--:|
| `ambient` | 28 | 25 | 24 | 24 |
| `chainsaw` | 11 | 37 | 21 | 10 |
| `elephant_call` | 9 | 14 | 59 | 2 |
| `gunshot` | 44 | 8 | 17 | 143 |

Full interactive results: <https://studio.edgeimpulse.com/studio/1109511/testing>

### Reading these numbers honestly — this is not a clean win

`elephant_call` recall jumped 33.2 points (37.0%→70.2%), but **total accuracy barely moved**
(56.2%→56.1%), and the confusion matrix shows why this is not simply "more elephant data made
the model better": `ambient` collapsed by the same order of magnitude it gained (43.6%→27.7%),
and the votes `elephant_call` gained came substantially from `ambient` and `chainsaw` rather
than from resolving a genuine ambiguity. `ambient`→`elephant_call` misroutes rose from 4/101 to
24/101; `chainsaw`→`elephant_call` misroutes rose from 7/79 to 21/79; `chainsaw`'s own recall
fell in step (55.7%→46.8%). This reads as the three classes reshuffling which way their
confusion gets misrouted, not as the decision boundaries actually sharpening.

Sixteen additional clips (a 4% increase in `elephant_call`'s pool) is too small a change to
plausibly cause a swing this large through data volume alone. The far more likely explanation
is the same one flagged as unresolved after the `vehicle` drop above: this model's four
remaining classes have enough real overlap in the MFE feature space that which class "wins" a
given ambiguous clip is sensitive to small perturbations in training data and/or random
initialization — ordinary run-to-run variance, not a trend. **No repeat run was done to
separate signal from variance here either, given the build deadline.** Anyone using this
model's per-class numbers should treat a single run's `elephant_call`/`ambient`/`chainsaw`
figures as having roughly ±15-20 points of run-to-run noise until multiple repeated runs are
averaged (not blended into a single reported number — see this document's no-averaging rule —
but used to establish an honest confidence interval before the next real decision is made on
this model).

## Result — retrain after widening all four classes' sourcing (2026-09-14, supersedes the run above)

Following the `elephant_call`-only widening above, the Freesound query lists for **all four**
classes were widened (`gunshot` 10→15 queries, `chainsaw` 8→13, `elephant_call` 12→18, plus a
brand-new 12-query forest/jungle-ambience pull for `ambient`, which had none before), and the
per-class `FREESOUND_CAP` was raised (`gunshot`/`chainsaw` to 200/400, `ambient` capped at 260
for the new supplement). This was a direct response to the request to source more data and try
to reach 80% recall on every class. The resulting dataset (1,977 clips total — see the Dataset
table above) was uploaded to project 1109511 and retrained twice: once with this project's
long-standing `autoClassWeights: False` default, and once with it flipped on via the
`--class-weights` CLI override, to see whether `ambient`'s new 700-clip majority (it is now
larger than the other three classes combined) was distorting the un-weighted result.

**Project 1109511 data for both runs: 1,838 training / 587 testing clips.**

### Variant A — `autoClassWeights` off (the locked default)

**Training job** (job 53769500, Edge Impulse's own training-time validation split, 368 clips):

| Variant | Loss | Accuracy |
|---|--:|--:|
| float32 | 1.0822 | 57.1% |
| int8 | 1.0852 | 56.5% |

**Held-out model test** (job 53769558 — a real `classify` job over the actual 587-clip test
split, never seen during training; `minimumConfidenceRating: 0.1`, true argmax accuracy):

| Class | Good/Total | Recall | `floor_status` |
|---|--:|--:|---|
| `gunshot` | 165/249 | **66.3%** | trained |
| `chainsaw` | 19/101 | **18.8%** | trained |
| `elephant_call` | 30/84 | **35.7%** | trained |
| `ambient` | 106/153 | **69.3%** | trained |

**Total: 320/587 correct = 54.5%** (four-class chance floor = 25%).

**Confusion matrix** (rows = true label, columns = predicted; `uncertain` was 0 for every row):

| True \ Predicted | `ambient` | `chainsaw` | `elephant_call` | `gunshot` |
|---|--:|--:|--:|--:|
| `ambient` | 106 | 10 | 13 | 24 |
| `chainsaw` | 55 | 19 | 11 | 16 |
| `elephant_call` | 38 | 11 | 30 | 5 |
| `gunshot` | 72 | 3 | 9 | 165 |

### Variant B — `autoClassWeights` on (`--class-weights` override)

**Training job** (job 53769747, same 368-clip validation split):

| Variant | Loss | Accuracy |
|---|--:|--:|
| float32 | 1.1148 | 51.1% |
| int8 | 1.1139 | 52.2% |

**Held-out model test** (job 53769815, same 587-clip real test split):

| Class | Good/Total | Recall | `floor_status` |
|---|--:|--:|---|
| `gunshot` | 173/249 | **69.5%** | trained |
| `chainsaw` | 14/101 | **13.9%** | trained |
| `elephant_call` | 54/84 | **64.3%** | trained |
| `ambient` | 76/153 | **49.7%** | trained |

**Total: 317/587 correct = 54.0%.**

**Confusion matrix:**

| True \ Predicted | `ambient` | `chainsaw` | `elephant_call` | `gunshot` |
|---|--:|--:|--:|--:|
| `ambient` | 76 | 8 | 36 | 33 |
| `chainsaw` | 41 | 14 | 26 | 20 |
| `elephant_call` | 20 | 6 | 54 | 4 |
| `gunshot` | 53 | 4 | 19 | 173 |

Full interactive results: <https://studio.edgeimpulse.com/studio/1109511/testing>

### Reading these numbers honestly — 80% was not reached on any class, and this is a mixed result

Neither variant comes close to the 80%-per-class target. Total accuracy did not improve over
the prior `elephant_call`-only run (56.1% → 54.5% / 54.0%) despite nearly doubling the dataset
(1,251 → 1,977 clips). The two variants tell a clear, consistent story once read together
rather than in isolation:

- **`ambient` volume genuinely helped**, but only without class weighting. Growing `ambient`
  from 366 to 700 clips (now the largest class by a wide margin) pushed its own recall from
  27.7% to 69.3% under `autoClassWeights: False` — the biggest single-class swing seen in this
  project's history that is plausibly a real data effect rather than run-to-run noise, given the
  scale of the volume change. But `autoClassWeights: True` immediately gives most of that gain
  back (69.3%→49.7%), because reweighting explicitly discounts the now-dominant class in the
  loss function — confirming the gain is a volume/prior effect, not a sharper decision boundary.
- **Class weighting trades `ambient` for `gunshot` and `elephant_call`.** Turning weighting on
  recovers `elephant_call` from 35.7% to 64.3% and lifts `gunshot` from 66.3% to 69.5%, both by
  countering `ambient`'s now-oversized prior — consistent with how `autoClassWeights` is
  documented to work. This is the expected, mechanical effect of reweighting against a skewed
  class distribution, not a data-quality finding.
- **`chainsaw` is not fixed by weighting, and its confusion is not concentrated on the majority
  class.** `chainsaw` regressed in both variants (55.7% in the prior 5-class run → 18.8% off /
  13.9% on), and under weights-on its confusion matrix row spreads across all three other
  classes almost evenly (`ambient` 41, `elephant_call` 26, `gunshot` 20) rather than piling onto
  `ambient`, the way a pure imbalance artifact would. If `ambient`'s volume were the only cause,
  reweighting away from `ambient` should have recovered most of `chainsaw`'s recall the way it
  recovered `elephant_call`'s — it did not (13.9% is *worse* than the 18.8% weights-off number).
  This points to a genuine data-quality problem introduced by the widened `chainsaw` Freesound
  queries, not a class-imbalance artifact. The most likely single cause: the `"power saw"`
  query alone contributed 138 of `chainsaw`'s 321 Freesound-sourced clips (see the Dataset
  section above), and that query almost certainly pulls in non-chainsaw power-tool audio
  (circular saws, table saws, angle grinders) that shares spectral characteristics with a
  chainsaw's engine drone but is acoustically distinct enough to confuse the model rather than
  reinforce it. This has not been verified by manually auditing the "power saw" clips — that
  audit is flagged as follow-up work below, not done as part of this pass, to avoid further
  blind retrain cycles.

**No further retrain was attempted after Variant B.** Two real, honestly-reported configurations
already establish the shape of the tradeoff (ambient-volume gain vs. weighting-driven
redistribution vs. an unresolved chainsaw data-quality regression); continuing to try
hyperparameter combinations in search of a better number would drift toward exactly the kind of
fishing-for-a-good-run this document's no-averaging/no-fabrication convention exists to prevent.
Which of Variant A or Variant B is left as the live model in project 1109511 depends on which
failure mode is more acceptable operationally: Variant A (weights off) favors `ambient`/`gunshot`
at the cost of `elephant_call` and `chainsaw`; Variant B (weights on) favors `gunshot`/
`elephant_call` — the class that also feeds the deterrence fusion decision — at the cost of
`ambient` and a further-regressed `chainsaw`. Given that `elephant_call` is the one acoustic
class this model feeds into the bandit/deterrence decision (see the class-scheme section above),
**Variant B (`autoClassWeights: True`) was left as the trained state of project 1109511** after
here — this is a judgment call about which failure mode matters more for the deployment,
not a claim that Variant B is a better model in the aggregate; the total accuracy figures above
show it is not.

## Result — after the chainsaw data-quality audit and the ambient-cap pullback (2026-09-15, supersedes the run above)

Following the `"power saw"` audit and the `AMBIENT_CAP` pullback documented in the Dataset
section above, the dataset was re-uploaded to project 1109511 and retrained. **Project 1109511
data for every run below: 1,775 training / 552 testing clips**, MFE DSP, the locked impulse
(`--skip-impulse` reused the existing dsp/learn blocks for runs after the first). Four separate
real training runs were executed against this identical dataset — not two, as an earlier
internal note believed; the actual sequence, reconstructed from this project's own job history,
is reported below run by run, **with no averaging across runs and no cherry-picking the best
one as "the" result**.

### Run A — `autoClassWeights` on

Feature job `53779616` (5.5 min) → training job `53779914` (2.7 min) → held-out classify job
`53780104` (2.7 min).

| Class | Good/Total | Recall |
|---|--:|--:|
| `ambient` | 82/152 | **53.9%** |
| `chainsaw` | 12/48 | **25.0%** |
| `elephant_call` | 54/76 | **71.1%** |
| `gunshot` | 185/276 | **67.0%** |

**Total: 333/552 = 60.3%.**

### Run B — `autoClassWeights` off

Feature job `53780286` → training job `53780518` → held-out classify job `53780713` (2.7 min).

| Class | Good/Total | Recall |
|---|--:|--:|
| `ambient` | 117/152 | **77.0%** |
| `chainsaw` | 2/48 | **4.2%** |
| `elephant_call` | 29/76 | **38.2%** |
| `gunshot` | 167/276 | **60.5%** |

**Total: 315/552 = 57.1%.** This reconfirms the earlier weights-off finding: `ambient` recall
is the best of any run here, and `chainsaw` collapses almost to nothing (4.2%, worse than a
25% four-class chance floor's naive per-class baseline would suggest for a class this small).

### Run C — `autoClassWeights` on (repeat of Run A's exact configuration)

Feature job `53780862` → training job `53781206` → held-out classify job `53781440` (8.2 min).

| Class | Good/Total | Recall |
|---|--:|--:|
| `ambient` | 112/152 | **73.7%** |
| `chainsaw` | 9/48 | **18.8%** |
| `elephant_call` | 41/76 | **53.9%** |
| `gunshot` | 145/276 | **52.5%** |

**Total: 307/552 = 55.6%.**

*(Between Run C and Run D, the EON Tuner 4-class re-run above (job `53782394`) executed, and a
duplicate feature-generation job storm — jobs `53785901`/`53785905`/`53785906`, all finished
`successful=False` — had to be waited out and did not produce a usable result before Run D.)*

### Run D — `autoClassWeights` on (currently the live trained state of project 1109511)

Feature job `53785969` (5.1 min) → training job `53786057` (3.8 min) → held-out classify job
`53786113` (2.7 min).

| Class | Good/Total | Recall |
|---|--:|--:|
| `ambient` | 92/152 | **60.5%** |
| `chainsaw` | 9/48 | **18.8%** |
| `elephant_call` | 54/76 | **71.1%** |
| `gunshot` | 173/276 | **62.7%** |

**Total: 328/552 = 59.4%.**

Confusion matrix:

| True \ Predicted | `ambient` | `chainsaw` | `elephant_call` | `gunshot` |
|---|--:|--:|--:|--:|
| `ambient` | 92 | 6 | 28 | 26 |
| `chainsaw` | 23 | 9 | 13 | 3 |
| `elephant_call` | 15 | 4 | 54 | 3 |
| `gunshot` | 80 | 3 | 20 | 173 |

Full interactive results: <https://studio.edgeimpulse.com/studio/1109511/testing>

### Reading these numbers honestly — three identically-configured runs, one dataset, a wide spread

Runs A, C, and D all use the exact same `autoClassWeights: True` configuration against the
byte-identical 1,775/552 dataset, differing only in Edge Impulse's own training-run randomness
(weight initialization, minibatch order). Laid side by side, the spread is large enough that
**quoting any single one of these three runs as "the" chainsaw or ambient number would be
misleading**:

| | Run A | Run C | Run D | spread |
|---|--:|--:|--:|--:|
| `ambient` | 53.9% | 73.7% | 60.5% | **19.8 points** |
| `chainsaw` | 25.0% | 18.8% | 18.8% | 6.2 points |
| `elephant_call` | 71.1% | 53.9% | 71.1% | 17.2 points |
| `gunshot` | 67.0% | 52.5% | 62.7% | 14.5 points |
| total | 60.3% | 55.6% | 59.4% | 4.7 points |

This is a stronger, now-quantified version of the "±15-20 points of run-to-run noise" caveat
already carried in this document from the `elephant_call`-widening run — it is no longer an
estimate from two differently-configured runs, it is a measurement from three repeated runs on
one fixed dataset and one fixed configuration. Total accuracy is comparatively stable (55.6%–
60.3%, a 4.7-point spread); per-class recall is not, and `ambient` and `elephant_call` swing by
nearly 20 points each depending on nothing but which run you happen to look at.

`chainsaw` is the one class where this run-to-run noise does **not** rescue a hopeful reading:
its highest observed value across all four runs (A/B/C/D) and the EON Tuner's best trial is
25.0% (Run A), and its range (4.2%–25.0%) never approaches the 80% target from any angle tried.
The `"power saw"` audit's data-quality fix (see above) did not produce a clean recovery — Run D,
trained on the corrected dataset, still lands at 18.8%, statistically indistinguishable from
Run C's 18.8% on the pre-fix-adjacent dataset. Whatever is limiting `chainsaw` recall on this
device's fixed 8 kHz/10 s/MFE pipeline, it was not resolved by removing the one clearly
mislabeled query.

Run D used the same `autoClassWeights: True` judgment call documented in the prior Result section
(favoring `elephant_call`, the class that also feeds the deterrence fusion decision, over
`ambient`). It was not claimed to be the best of the four runs by any metric other than
recency — Run A's total (60.3%) and `chainsaw` recall (25.0%) were both marginally higher.
**Run D is no longer the live trained state of project 1109511** — see the MFE-vs-MFCC section
immediately below, whose final run (Run E) superseded it. **The honest conclusion, across every
configuration tried in this entire session — five hand-tuned MFE runs, the EON Tuner's automated
search, and two independent data-quality interventions — is that the 80%-per-class target was
not reached on any class, and `chainsaw` remains the persistent bottleneck, never exceeding 25%
recall under any real, verified condition.**

## Result — MFE vs MFCC x `autoClassWeights` on the current dataset (2026-09-22, supersedes Run D as the live state)

The DSP A/B section above (MFE vs MFCC) was measured on the older rebalanced+XIAO 7-class
dataset, not the current post-audit 1,775/552 4-class one — an earlier internal note believed a
comparison existed on the current dataset, but it did not until this run. All four runs below
share the identical 1,775/552 dataset; `--dsp mfcc` requires a full impulse rebuild (frame count
13 vs MFE's 40), so `--skip-impulse` was only used for the second run of each DSP-type pair.

### MFCC, `autoClassWeights` on

Feature job `54003784` (4.5 min) -> training job `54003892` (2.1 min) -> held-out classify job
`54003929` (2.4 min). (This exact configuration was run twice in immediate succession — an
earlier feature/train/classify triple, jobs `54003532`/`54003674`/`54003715`, produced numbers
identical to the digit, including training-time validation loss matching to 16 significant
figures. That is not plausible for two independently-initialized training runs and is most
likely Edge Impulse returning a cached/deduped result for the second invocation, consistent with
the duplicate-job behavior this project has seen before on this network. Only one data point is
counted here, not two.)

| Class | Good/Total | Recall |
|---|--:|--:|
| `ambient` | 107/152 | **70.4%** |
| `chainsaw` | 11/48 | **22.9%** |
| `elephant_call` | 42/76 | **55.3%** |
| `gunshot` | 146/276 | **52.9%** |

**Total: 306/552 = 55.4%.**

### MFCC, `autoClassWeights` off

Feature job `54013922` (0.3 min, reused MFCC impulse via `--skip-impulse`) -> training job
`54013926` (2.1 min) -> held-out classify job `54013978` (0.7 min).

| Class | Good/Total | Recall |
|---|--:|--:|
| `ambient` | 126/152 | **82.9%** |
| `chainsaw` | 2/48 | **4.2%** |
| `elephant_call` | 46/76 | **60.5%** |
| `gunshot` | 124/276 | **44.9%** |

**Total: 298/552 = 54.0%.**

### Run E — MFE, `autoClassWeights` on (rebuild; now the live trained state of project 1109511)

Feature job `54014006` (3.8 min) -> training job `54014102` (2.4 min) -> held-out classify job
`54014192` (2.1 min).

| Class | Good/Total | Recall |
|---|--:|--:|
| `ambient` | 90/152 | **59.2%** |
| `chainsaw` | 8/48 | **16.7%** |
| `elephant_call` | 54/76 | **71.1%** |
| `gunshot` | 168/276 | **60.9%** |

**Total: 320/552 = 58.0%.**

### The full grid, and why MFE stays the locked DSP block

| Config | `ambient` | `chainsaw` | `elephant_call` | `gunshot` | total |
|---|--:|--:|--:|--:|--:|
| MFE, weights on (Run D) | 60.5% | 18.8% | 71.1% | 62.7% | 59.4% |
| MFE, weights off (Run B) | 77.0% | 4.2% | 38.2% | 60.5% | 57.1% |
| MFCC, weights on | 70.4% | 22.9% | 55.3% | 52.9% | 55.4% |
| MFCC, weights off | 82.9% | 4.2% | 60.5% | 44.9% | 54.0% |
| MFE, weights on (Run E, live) | 59.2% | 16.7% | 71.1% | 60.9% | 58.0% |

MFCC's only advantage anywhere in this grid is `chainsaw`, and only against the weights-on MFE
runs (+4.1 points over Run D, +6.2 over Run E) — never against the weights-off MFE runs, where
MFCC and MFE tie at 4.2%. That small chainsaw gain costs `elephant_call` 15.8 points against
either weights-on MFE run (Run D and Run E tie at 71.1%), `gunshot` 8.0-9.8 points, and 2.6-4.0
points of total accuracy. Given `elephant_call`'s dual role (it also feeds the deterrence fusion
decision) and this project's stated priority — `elephant_call`/`gunshot`/`chainsaw` matter more
than raw total, but not in a way that justifies a 15.8-point `elephant_call` loss for a few
points of `chainsaw` — MFE remains the better DSP block, reconfirming the older DSP A/B
section's verdict on a dataset where it had never actually been tested. Project 1109511 was
rebuilt back onto MFE (Run E) so its live state reflects this conclusion rather than being left
on the worse MFCC config that happened to run last.

Run E's numbers track Run D's closely on `elephant_call` (71.1%, identical 54/76) and are within
a few points on `ambient`/`chainsaw`/`gunshot` — a fifth data point consistent with the
run-to-run-variance caveat below, not a contradiction of it.

## Result — historical: final 5-class run before the `vehicle` drop (superseded 2026-09-14)

This is the real, live run after the 2026-09-13 chainsaw/vehicle data widening: 5-class
scheme, 10.0 s window, the locked architecture and DSP above. Edge Impulse's own
training-run log reports **1,729 training / 536 testing** clips read for this job;
summing the per-class train/test counts in the Dataset table above gives 1,674 / 495
instead — a larger version of the same kind of discrepancy the pre-widening run already
had (there it was 14 training / 1 testing clip; see "Why the manifest's per-class test
count is a floor, not the real count" above for the now-identified mechanism — the ledger
accumulates clips across runs with different seeded samples, so the manifest's latest-run
counts undercount what is actually resident and being tested). The held-out numbers below
are Edge Impulse's own `classify` job output (536 real held-out clips, matching the
training log's testing count) and are internally consistent with each other; they are the
authoritative real-world test-set sizes, not the manifest's.

This run was reproduced twice with identical results (once as the direct widened-data
retrain, once again after repairing the manifest — see below), and a third variant with
`autoClassWeights: True` was also run as a genuine re-test (not previously tried on this
5-class roster) and discarded — see the addendum at the end of this section.

**Training job** (job 53728634, from Edge Impulse's own training-time validation split):

| Variant | Loss | Accuracy |
|---|--:|--:|
| float32 | 1.2211 | 52.0% |
| int8 | 1.3017 | 52.6% |

**Held-out model test** (job 53728654/53728766 — a real `classify` job run over the actual
test split, 536 clips, never seen during training; `minimumConfidenceRating: 0.1` so this
is true argmax accuracy, not Edge Impulse's confidence-bucketed number):

| Class | Good/Total | Recall | `floor_status` | vs. pre-widening |
|---|--:|--:|---|--:|
| `ambient` | 64/101 | **63.4%** | trained | +17.9 |
| `gunshot` | 110/181 | **60.8%** | trained | −3.8 |
| `elephant_call` | 40/79 | **50.6%** | trained | −15.2 |
| `vehicle` | 55/99 | **55.6%** | trained | **+27.9** |
| `chainsaw` | 18/76 | **23.7%** | trained | **+6.1** |

**Total: 287/536 correct = 53.5%** (five-class chance floor = 20%).

**Confusion matrix** (rows = true label, columns = predicted; `uncertain` was 0 for every
row at `minimumConfidenceRating: 0.1`):

| True \ Predicted | `ambient` | `chainsaw` | `elephant_call` | `gunshot` | `vehicle` |
|---|--:|--:|--:|--:|--:|
| `ambient` | 64 | 2 | 10 | 13 | 12 |
| `chainsaw` | 22 | 18 | 9 | 3 | 24 |
| `elephant_call` | 22 | 1 | 40 | 2 | 14 |
| `gunshot` | 51 | 4 | 15 | 110 | 1 |
| `vehicle` | 23 | 5 | 10 | 6 | 55 |

Full interactive results: <https://studio.edgeimpulse.com/studio/1109511/testing>

### Reading these numbers honestly (historical, pre-`vehicle`-drop)

This is the direct outcome of widening chainsaw's Freesound queries from 2 to 8 and
vehicle's from 4 to 10 (plus a new ESC-50 "engine" supplement for vehicle), specifically to
address these two classes being the model's weakest (see the prior Result numbers in the
"vs. pre-widening" column). **`vehicle` responded strongly** — 27.7% → 55.6%, a real
doubling, and the confusion matrix shows why: it's now most often confused with `ambient`
(23/99) rather than scattered everywhere, a single dominant confusable pair rather than a
diffuse failure. **`chainsaw` improved only modestly** — 17.6% → 23.7% — and its confusion
pattern changed shape rather than just shrinking: it is now concentrated in two confusable
pairs, `vehicle` (24/76, the single largest bucket) and `ambient` (22/76), together
accounting for 60% of its errors. That chainsaw's own widened data made it *more* likely to
be confused specifically with vehicle (whose data also grew this run) rather than less is a
real signal that these two classes' Freesound-sourced audio — both sustained
mechanical/engine drones — sit close together in MFE feature space at this window length;
more volume alone did not separate them. `elephant_call` and `ambient` moved too (−15.2 and
+17.9) despite their own data being unchanged in this run — a reminder that in a 5-class
softmax, any class's decision boundary can shift when another class's data changes, so a
per-class delta is never fully attributable to that class's own data alone. Total accuracy
(53.5%) is reported for completeness only; it is not the metric this project optimizes for
and should not be read as summarizing "the model got better" — chainsaw's continued weakness
is the operative fact for that class specifically.

### `autoClassWeights` re-test on the current roster (2026-09-13) — reconfirmed OFF

The original OFF-lock (see the section above) was measured with `boar_call`/`predator_call`
still in the roster; since both were later dropped entirely, that justification does not
automatically transfer to today's 5-class problem, so it was re-tested rather than assumed.
Same widened data, `--skip-impulse` (identical DSP features), retrain-only comparison:

| Class | Weights OFF (kept) | Weights ON | Delta |
|---|--:|--:|--:|
| `chainsaw` | 23.7% | 17.1% | −6.6 |
| `vehicle` | 55.6% | 48.5% | −7.1 |
| `gunshot` | 60.8% | 64.1% | +3.3 |
| `ambient` | 63.4% | 55.4% | −8.0 |
| `elephant_call` | 50.6% | 50.6% | 0.0 |

Weights ON costs both of this pass's target classes (chainsaw, vehicle) real recall for a
small gunshot gain — the wrong trade for the work it was doing. **Reconfirmed:
`autoClassWeights: False`.** The production model in 1109511 was retrained a final time with
weights off after this experiment, so the numbers in the Result section above (and the live
model in the project) reflect weights-off, not the experiment.

## Result — corrected corpus after a full integrity audit (2026-09-23, supersedes the section below)

The section that follows this one reported 92.8% overall and 77.9% chainsaw recall. Both figures
are withdrawn. Auditing the frozen split directly — rather than reasoning about filenames — turned
up three further defects, documented in the 2026-09-23 amendment to
`docs/decisions/0025-acoustic-recording-level-split-integrity.md`:

1. Three byte-identical audio payloads spanned train and test under different filenames, which no
   naming rule can see. `build_index.py` now hashes decoded frames and unions the group keys; 25
   payloads proved to be held under more than one key.
2. Freesound id 410552 was in the corpus as both `ambient` and `gunshot` over identical audio. It
   is a rifle shot recorded in forest at 15 m, confirmed from the uploader's description and
   independently from the waveform (two impulsive events over near-silence, frame-RMS max/median
   72:1). A gunshot inside the `ambient` class teaches directly against the gunshot/ambient
   confusion the model is being asked to resolve. It is quarantined.
3. The Zenodo ingest's peak normalisation amplified a small source DC offset into a median 0.32
   against 0.000 for every other corpus, and larger on chainsaw than ambient — a per-source
   constant a model could separate on without listening. Fixed by removing DC before normalising.

Both splits now pass `audit_dataset.py --full` with zero fatal issues.

| class | recall | 95% CI | precision | F1 | n |
|---|---|---|---|---|---|
| ambient | 95.2% | [93.6, 98.4] | 93.5% | 0.94 | 236 |
| chainsaw | 86.5% | [82.0, 96.4] | 85.5% | 0.86 | 68 |
| elephant_call | 93.4% | [88.6, 100.0] | 90.1% | 0.92 | 58 |
| gunshot | 93.4% | [88.9, 95.3] | 96.4% | 0.95 | 243 |
| **overall** | **93.3%** | | | | 605 |

Field slice: ambient 97.9% (n=39), elephant_call 95.9% (n=29). Chainsaw and gunshot field recall
are not reportable (n=2 and n=1).

**Chainsaw reads as 77.9% → 86.5%, and that is not a controlled comparison.** Quarantining 410552
and merging the duplicate groups changed group membership, so the seeded split redrew and chainsaw
is now measured on a different 68 recordings. The two intervals overlap substantially. Part of the
movement is likely real — removing a rifle shot from `ambient` should reduce chainsaw→gunshot
confusion, and it fell from 10.6% to 2.6% — but `elephant_call` and `gunshot` each dropped about
1.8 points in the same run, which is the signature of a changed test set rather than a systematic
gain. Quote 86.5% as the current figure, not as an improvement of 8.6 points.

### The long-range ARU corpus did not help, and the first attempt was actively harmful

Zenodo 5824433 (Stefanakis et al., EUSIPCO 2022) was added to attack the chainsaw shortfall: 8 kHz
native, SWIFT recorders in real forest, human-annotated, CC-BY-4.0. Added train-only against the
byte-identical 605-file test set, it produced this:

| | baseline | +Zenodo v1 (436 cs / 163 amb) | +Zenodo v2 (392 cs / 545 amb) |
|---|---|---|---|
| overall | **93.3%** | 90.8% | 90.9% |
| chainsaw recall | 86.5% | 87.6% | 87.4% |
| chainsaw precision | **85.5%** | 68.0% | 71.5% |
| ambient recall | **95.2%** | 88.3% | 89.3% |
| field ambient recall | **97.9%** | 57.9% | 68.7% |

The roughly one point of chainsaw recall is inside the confidence interval in both runs. The costs
are not.

The first hypothesis was internal imbalance. These are SWIFT units in one forest, so they share a
distinctive noise floor, and within it chainsaw outnumbered ambient 2.7:1 — apparently the model
learning the recorder rather than the saw. On the deployment noise floor, 42% of genuine forest
ambience came back as `chainsaw`.

So the ingest was rebalanced to 392 chainsaw against 545 ambient, inverting the ratio, and v2
tests that prediction. It moved in the predicted direction and nowhere near far enough: field
ambient recovered 10.8 points but remains 29 points below baseline, and chainsaw precision
recovered 3.5 points but remains 14 below. The imbalance was a contributing factor, not the cause.
What is left is a genuine domain shift — Mediterranean forest, 2016-18, autonomous units — that
survives rebalancing.

**Verdict: the corpus is not used.** Testing further variants against the same 605-file test set
would select for a lucky draw rather than measure anything, so two falsified attempts is where this
stops. `build_index.py` excludes `zenodo_aru` by default and `--include-source` re-admits it; the
audio stays on disk because the licence is clean and a future domain-adaptation attempt may want
it.

The reason this mattered enough to test twice: for a system that pages a forest officer on chainsaw
detections, a precision collapse is a worse failure than the 13.5% of chainsaws currently missed.
It trades a detection gap for alert fatigue, which ends with the system ignored. It is also the same
class of defect as the DC offset and the earlier `xiao_esp32s3` artifact — a per-source property
that correlates with a label — which is why a new corpus is now checked against the per-source
DC/RMS/clipping table and evaluated on the field slice before it is trusted.

## Result — recording-level evaluation and an AudioSet-pretrained backbone (2026-09-23)

Measured by `ml/acoustic/harness/`, outside Edge Impulse, on a split grouped by source recording
(607 held-out recordings; see `docs/decisions/0025-acoustic-recording-level-split-integrity.md`).
These are **not** comparable to the Edge Impulse numbers above, which used a file-level split.

The control is the production recipe itself — the locked MFE front end and
`conv1d(16) -> conv1d(32) -> dense(24)` — rebuilt and run on the same split, so the comparison
isolates the backbone rather than crediting it with the dataset rebuild.

| Class | MFE control (recall) | Cnn14 + MLP | Cnn6 + MLP | n |
|---|--:|--:|--:|--:|
| `ambient` | 72.9% | **94.2%** | 88.9% | 236 |
| `chainsaw` | 77.9% | **77.9%** | 80.3% | 68 |
| `elephant_call` | 86.1% | **95.3%** | 95.0% | 60 |
| `gunshot` | 87.4% | **95.1%** | 96.7% | 243 |
| **overall** | **80.6%** (78.3–84.2) | **92.8%** (92.3–93.1) | **91.7%** (90.9–92.6) | 607 |

Per-class recall with a 95% bootstrap CI over resampled test recordings, and precision, for
Cnn14 + MLP: `ambient` 94.2% [90.3, 96.6] / 92.8%; `chainsaw` 77.9% [69.4, 88.3] / 85.3%;
`elephant_call` 95.3% [91.7, 100] / 98.0%; `gunshot` 95.1% [92.1, 97.6] / 93.5%.

### `chainsaw` is the one place the "data ceiling" verdict holds

The Exploration History concluded "data ceiling, not capacity ceiling" from two small nets tying.
On a clean split that conclusion is wrong for three classes and right for one. An AudioSet-pretrained
backbone lifts `ambient` by 21.3 points, `elephant_call` by 9.2 and `gunshot` by 7.7 — those were
capacity ceilings, and the tie between two similar small nets could not have revealed it.

`chainsaw` does not move at all. An 81M-parameter backbone pretrained on a corpus whose ontology
contains `Chainsaw` (/m/01j4z9) scores 77.9%, exactly what the 2-conv net from scratch scores. Two
further probes agree: adding 254 AudioSet chainsaw recordings to training (nearly doubling the
class, test set held byte-identical) changed recall by −1.1 points, within noise; and no decision
threshold reaches 85% recall without giving up most of the precision headroom. The missed saws
split between `ambient` (11.5%) and `gunshot` (10.6%) — quiet or distant cutting, and impulsive
onsets.

That AudioSet augmentation failed is consistent rather than surprising: the backbone was pretrained
on AudioSet, so AudioSet chainsaw audio carries little the representation has not already seen.
What `chainsaw` needs is audio from a *different* distribution — real saws at real distances on the
deployment hardware — not more of the same corpus.

### Operating point is a deployment decision, not a modelling one

`chainsaw` at argmax gives 77.9% recall at 85.3% precision. Lowering its threshold to 0.10 reaches
**85.3% recall at 76.3% precision** — 18 false positives instead of 8, over 607 recordings. Which
of those is correct depends on whether a missed illegal-logging event or an unnecessary patrol is
the costlier error in Kothamangalam, which is the DFO's call to make and not a default this
repository should silently pick.

### Backbone choice

Cnn6 (5.9M params, 512-d) trails Cnn14 (81M, 2048-d) by 1.1 points overall and is the only one of
the two that could plausibly run on the QRB2210. It is also *better* on `chainsaw` (80.3% recall at
92.0% precision). It is worse where it matters most, though: `elephant_call` precision falls from
98.0% to 77.9%, and `elephant_call` is the only class that feeds the deterrence decision in
`device/mpu/services/reflex_loop.py`, so roughly one deterrent firing in five would be spurious.
Neither backbone has been exported or benchmarked on-device yet; latency, RAM and flash on the
QRB2210 are unmeasured, and no `.eim` exists.

## Caveats — required whenever any number from this project is quoted

> **Every Edge Impulse accuracy in this file was measured on a file-level split and is
> optimistic.** This corpus contains *recordings*, each present many times over: the
> preprocessing pipeline emits several windows and gain variants per source file, ESC-50 is cut
> from Freesound (so five chainsaw recordings appear under both corpora), and the project's own
> field captures are chunked — `..._bg.1` through `..._bg.35` are consecutive slices of one
> continuous session, not 35 captures. Splitting on the file therefore put near-duplicates of the
> same audio on both sides of the boundary: 25.4% of `elephant_call` leaked at the variant level,
> and five chunks of the one chainsaw field session sat in train while 38 sat in test, which is
> why its field slice read a flawless 100%.
>
> `ml/acoustic/harness/` re-runs the evaluation with splits grouped by source recording, and
> `freeze_split.py` fails hard if any recording appears on both sides. The numbers below are kept
> as the record of what the Edge Impulse project reported, not as held-out accuracy. See
> `docs/decisions/0025-acoustic-recording-level-split-integrity.md`.

1. **`elephant_call`'s largest source has no license.**
   `github.com/HiruDewmi/Audio-Classification-for-Elephant-Sounds` supplies 313 of
   `elephant_call`'s 410 clips; the repository has no `LICENSE` file and no terms stated in
   its README (GitHub's own repository API reports `license: null`). This is usable for the
   experiment described here, but is flagged in the manifest per-clip
   (`"license": "none (GitHub repo has no LICENSE file)"`) and must be resolved — cleared,
   replaced, or the class re-sourced — before any production/commercial licensing gate.
2. **Most of this audio was not captured on this project's own INMP441 in Kerala forest
   conditions.** Only the XIAO ESP32S3 field-capture clips (31–73 per class, see the
   Dataset table) are project-owned recordings, and even those come from a different
   microphone (XIAO's onboard PDM MEMS mic, not the INMP441) — a real domain-shift risk
   between this training data and the deployed hardware's actual audio characteristics.
   This closes *"a 4-class acoustic model exists, trained on a mix of real licensed public
   data and real field captures"*, not *"this model is proven on the deployed INMP441's own
   audio."* Those two claims travel separately.
3. **The elephant-rumble low end is not actually captured.** Rumble fundamentals sit at
   roughly 8–34 Hz; an MFE block's lowest mel band sits far above that, so the model sees
   rumble harmonics and overtones, never the fundamental. This is consistent with
   `/CONTEXT.md`'s architecture (the INMP441 is scoped to frequencies above 60 Hz; the
   geophone handles low-frequency/infrasound detection), not a defect introduced here — but
   it means `elephant_call` is not infrasound detection, regardless of how well it scores.
4. **Freesound clip relevance rests on uploader tagging, not expert verification**, across
   every class that draws from it (`gunshot`, `chainsaw`, `vehicle`, `elephant_call`). Clips
   were filtered by license, search query, and duration — not individually listened through.
5. **The `"power saw"` query was audited and dropped (2026-09-15); `chainsaw` still did not
   recover.** This caveat previously flagged `"power saw"` — which alone contributed 138 of
   `chainsaw`'s 321 Freesound clips at the time — as an unverified suspect for the collapse to
   18.8%/13.9% documented in the "Result — retrain after widening all four classes' sourcing"
   section. That audit has since been done: all 136 clips the query pulled were manually
   reviewed, and it was confirmed off-target — mostly synthesizer "sawtooth waveform" demos and
   generic factory/mechanical-impact sound-effects content, not other power tools as guessed,
   and not real chainsaw audio either way (see "Chainsaw data-quality audit" under the Dataset
   section above). The query was dropped and the remaining chainsaw query list widened from 13
   to 19 real chainsaw-specific queries. **This did not produce a clean recovery.** Across the
   four post-audit training runs in the current Result section, `chainsaw` recall ranges
   18.8%–25.0% — the same range as the pre-audit runs, and in two of the three
   `autoClassWeights`-on runs (Runs C and D) identical to 18.8% within measurement noise.
   Whatever limits `chainsaw` on this pipeline was not primarily the `"power saw"` contamination;
   see the new run-to-run-variance caveat below and this document's honest read that `chainsaw`
   has never exceeded 25% recall under any real, verified configuration tried.
6. **This model's per-class numbers swing by 15-33 points between consecutive retrains on
   nearly the same data, and the cause is not fully diagnosed.** The `vehicle`-drop retrain
   scored `elephant_call` at 37.0% (down from 50.6%-58.0% in the two runs immediately before
   the drop) while `ambient` scored 43.6%; widening `elephant_call`'s Freesound sourcing by
   just 4% (394→410 clips) and retraining then swung `elephant_call` to 70.2% while `ambient`
   fell to 27.7% and `chainsaw` fell from 55.7% to 46.8% — see both Result sections'
   "Reading these numbers honestly" subsections above for the full confusion-matrix evidence.
   Total accuracy barely moved across that second swing (56.2%→56.1%), which argues these are
   the same four classes reshuffling which way their mutual confusion gets routed, not a real
   change in model quality. **No repeat run was done at either point to separate signal from
   variance**, given the build deadline this work is under. Because `elephant_call`
   is the one class that also feeds the deterrence fusion decision, treat any single run's
   `elephant_call`/`ambient`/`chainsaw` numbers as having roughly ±15-20 points of run-to-run
   noise until repeated runs are done. `chainsaw` briefly recovered to 55.7% after the
   `vehicle` drop, then fell again to 46.8% after the `elephant_call`-only widening and further
   to 18.8%/13.9% after the all-four-classes widening — see the caveat above on that most
   recent drop, which (unlike the earlier swings in this item) has a specific diagnosed
   likely cause rather than being attributed to undifferentiated run-to-run variance.
7. **`boar_call` and `predator_call` were dropped from the wire scheme, not merely
   under-performing.** See the class-scheme section above for the full history and exact
   numbers. Any future attempt to revive either class should start from that section rather
   than re-running the same exploration from scratch.
8. **`vehicle` was dropped 2026-09-14 after real field data exposed a chainsaw/vehicle
   acoustic collision** (chainsaw held-out recall collapsed to 0.0%, corroborated by the
   training-time validation confusion matrix, not just the held-out split). See the
   class-scheme section above for the full history. The raw audio stays cached locally, so
   `vehicle` can be re-uploaded from cache if it is ever revived — but reviving it without
   also addressing the underlying MFE-feature-space overlap with `chainsaw` (a different DSP,
   window length, or non-Freesound audio source) would likely reproduce the same collision.
9. **`predator_call` (when it was still in scope) lumped lion, leopard, and tiger into one
   label** — a coarser distinction than a real predator-identification system would want,
   moot now that the class is dropped but worth remembering if it is ever revived.
10. **Window-length sweep candidates are not sample-for-sample comparable.** Test-set sizes
   for the same class shift across the five window candidates (e.g. `vehicle`'s test set
   was 47 clips at 3.0 s/10.0 s but only 7 at 4.0 s/6.0 s/8.0 s) because re-cropping at a
   different window length changes how many non-overlapping windows fit inside each raw
   source clip. Only per-class recall percentage is the fair comparison across candidates,
   never the raw good/total counts. (The sweep itself, and its `vehicle` numbers, predate
   the 2026-09-14 drop and are kept as-is — they were real measurements at the time.)
11. **Not deployed.** No acoustic inference runs on this project's hardware yet. This closes
    the training half of the gap `docs/KNOWN_GAPS.md` tracks, not the deployment half — see
    that file's entry for exporting this model and wiring it into `handle_acoustic_event()`
    (a separate, deferred Track B change).
12. **Performance Calibration was investigated and is not part of this pipeline.** Edge
    Impulse's own documentation confirms it is a Studio-UI-only feature — there is no REST
    API to trigger a calibration run, retrieve its synthetic continuous-audio results, or
    fetch the tuned post-processing parameters (detection threshold, averaging window,
    suppression period) programmatically. Both training scripts in this project are pure
    API automation (see Reproducing above), so this is out of reach for them by construction,
    not by omission. The feature's own docs also describe it as designed for detecting a
    specific event against a background/silence state (e.g. keyword spotting), "as opposed
    to classifying ambient conditions" — a partial but not exact fit for a five-way
    classifier where `ambient` is itself one of the trained classes rather than a generic
    background state. If a calibrated operating point is wanted, it would need to be run
    manually in the Edge Impulse Studio UI against project 1109511 and the result transcribed
    here by hand — not attempted as part of this pass.
13. **Run-to-run variance on an identical dataset and configuration is now directly measured,
    not just inferred.** Caveat 6 above documents swings between *different* retrains (new
    data, different `autoClassWeights` setting). The four runs in the current "Result — after
    the chainsaw data-quality audit and the ambient-cap pullback" section include three
    (Runs A, C, D) that share the exact same 1,775/552 dataset and the exact same
    `autoClassWeights: True` configuration, differing only in Edge Impulse's own training
    randomness. Their spread: `ambient` 53.9%–73.7% (19.8 points), `elephant_call` 53.9%–71.1%
    (17.2 points), `gunshot` 52.5%–67.0% (14.5 points), `chainsaw` 18.8%–25.0% (6.2 points),
    total accuracy 55.6%–60.3% (4.7 points). **Any single run's per-class number should be read
    against this spread, not treated as a precise measurement of the model's true per-class
    recall.** Total accuracy is comparatively stable and is the more trustworthy number of the
    two; per-class recall is not, for every class except `chainsaw` (whose recall is
    consistently low rather than consistently variable). Run E (MFE, weights on — see the
    MFE-vs-MFCC section, now the live trained state of project 1109511) is a fifth data point in
    this same family: `elephant_call` lands exactly on Run D's 71.1%, and `ambient`/`chainsaw`/
    `gunshot` fall within a few points of Run D, inside the spread already documented here.
14. **A real MFE-vs-MFCC x `autoClassWeights` comparison on the current 4-class dataset was run
    2026-09-22** (see the Result section above) — the older DSP A/B section higher up this
    document predates the chainsaw-audit/ambient-pullback dataset and was never actually
    re-verified against it until this run. MFE remains superior on every class except `chainsaw`,
    where MFCC's edge (+4.1 to +6.2 points) does not offset its cost to `elephant_call` (-15.8
    points) and `gunshot` (-8.0 to -9.8 points). One of the two nominally-identical MFCC-weights-on
    training invocations in that section produced results matching the other to 16 significant
    figures of validation loss — almost certainly a cached/deduped job rather than an independent
    retrain, and is reported as one data point, not two.

## Reproducing

```
export EI_API_KEY=ei_...          # not stored in this repo
export EI_PROJECT_ID=1110036      # production (ADR 0032); use 1109511 only to reproduce the
                                  # historical MFE runs recorded in the Result sections above
export FREESOUND_API_KEY=...      # https://freesound.org/apiv2/apply/
python scripts/edge_impulse_upload_acoustic.py
python scripts/edge_impulse_train_acoustic.py
```

Both scripts accept `--clip-seconds <L>` to reproduce any window-sweep candidate against a
scratch project instead of production; `edge_impulse_train_acoustic.py` additionally accepts
`--dsp {mfe,mfcc}` and `--learn {scratch,transfer_kws_mobilenetv1_a1_d100,
transfer_kws_mobilenetv2_a35_d100,transfer_kws_conv2d_tiny}` to reproduce the DSP A/B and
transfer-learning attempts described above.

`ml/datasets/acoustic/raw/` (gitignored) caches downloaded and normalized audio so a re-run
does not re-fetch or re-query Freesound; `dataset_manifest.json` in this directory is
committed and records the exact clip selection — source, license, split, sha256 of the
normalized payload — so the dataset behind any reported number is reproducible from a fresh
clone even though the raw audio itself is not, and even though a live Freesound search could
return different results on a later run.

`edge_impulse_upload_acoustic.py --only <label>` (repeatable) restricts a run to specific
classes for a quick iteration — but it narrows the manifest write to only the touched
classes rather than merging into the prior manifest state, so a `--only`-restricted run
silently drops every other class's provenance tracking (see "Why the manifest's per-class
test count is a floor" above for how this actually played out). Run without `--only` before
trusting the manifest for anything beyond the classes you just touched.
`edge_impulse_train_acoustic.py --class-weights` overrides the locked `AUTO_CLASS_WEIGHTS =
False` default for a one-off re-test; `--skip-impulse` reuses the current impulse's
already-generated features instead of rebuilding the DSP block, useful for a training-only
A/B like the class-weights re-test above.

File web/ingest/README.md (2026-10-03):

# web/ingest

Bridges ChirpStack's MQTT uplink stream into Supabase. Subscribes to
`application/{id}/device/{devEui}/event/up`, decodes the node's raw frame
(FPort 10, ADR 0031) in `src/payload.ts`, and writes rows into `nodes`,
`events`, and `health` per `web/backend/schema.sql`. No ChirpStack payload
codec is needed - leave the device profile's codec empty.

## Local setup

1. Stand up ChirpStack locally - [`web/chirpstack/`](../chirpstack/) has the
   whole stack and its setup steps. Region IN865 by default.
2. Copy `.env.example` to `.env` and fill in:
   - `SUPABASE_URL` / `SUPABASE_SERVICE_ROLE_KEY` - from the Supabase project
     settings. The service-role key bypasses RLS; keep it out of git and out
     of the frontend.
   - `CHIRPSTACK_APPLICATION_ID` - the application ID from the ChirpStack UI
     (Tenant → Applications), or several separated by commas. Optional, but
     recommended once you have more than one test application on the same
     broker.
   - `MQTT_CLIENT_ID` - optional, defaults to `eletect-ingest`. The broker
     keeps a queue per client ID, so two bridges must never share one.
3. Install dependencies and run:
   ```
   npm install
   npm run dev
   ```

## What it does

- On every uplink, registers the node if it hasn't been seeded yet (keyed on
  Device EUI) and moves `last_seen`. A seeded node keeps its name; an
  `offline` node goes back to `online`.
- **Event frame** -> an `events` row: species from the class byte (none for a
  seismic-only alert or a multi-species node), confidence, a short `action`
  label, and the decoded frame plus RSSI/SNR/fCnt in `events.uplink`.
  Priority is `high` for camera-confirmed wildlife and for gunshot/chainsaw,
  `normal` for a seismic-only alert. A node that sets the no-retreat flag
  makes it `critical`. `high` and `critical` fan out through `send-alert`.
- **Status frame** -> a `health` row with battery mV, uptime, geophone and
  home-test flags in `metrics`.
- A frame the node re-sent (same `seq` from the same node within 15 minutes)
  is dropped, so one event is one row.
- A pre-decoded `object` (test devices, the command below) is still accepted:
  `battery_pct` / `solar_w` / `temp_c` make a `health` row and a `species`
  field makes an `events` row.

- A write Supabase refuses or never answers is retried with backoff (2 s
  doubling to 1 min) for up to 30 minutes, then logged as given up. The
  duplicate check above makes a retry of a write that did land harmless.
- The MQTT session is persistent and subscribed at QoS 1, so uplinks that
  arrive while the bridge is down are queued by the broker and delivered when
  it reconnects. That only holds if ChirpStack publishes at QoS 1
  (`[integration.mqtt] qos=1`) and Mosquitto persists its queue across its own
  restarts - both are set in [`web/chirpstack/`](../chirpstack/).

Run the decoder tests with `npm test`.

## Running it for real

In the field the bridge runs as the `eletect-ingest` service in
[`web/chirpstack/docker-compose.yml`](../chirpstack/docker-compose.yml), built
from this directory's `Dockerfile` (compiled JS, no dev dependencies,
non-root) and restarted automatically. Its secrets come from this directory's
`.env`, which is not committed. After changing code here:

```
cd ../chirpstack
docker compose up -d --build eletect-ingest
docker compose logs -f eletect-ingest
```
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

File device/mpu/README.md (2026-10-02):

# MPU — QRB2210 (event cognition, Debian/Python)

Vision detector (Adreno/OpenCL), log-odds fusion, contextual-bandit deterrence, SQLite experience,
Bridge RPC, LoRa uplink. On-device vision model in `models/`. Bridge function signatures are
frozen against [bridge/schema.md](bridge/schema.md) — that file, not this README, is the source of
truth for what each function does; both sides (`device/mcu`, here) are hand-written against it
independently (`ENGINEERING_CONVENTIONS.md` §6).

## Two build paths — read this before touching either
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

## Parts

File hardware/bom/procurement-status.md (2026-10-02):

# EleTect X — Procurement Status (live tracker)

Supersedes the ✅/🛒 markers in `bom.md` for current status; `bom.md` stays the spec/pricing reference.
Snapshot taken **28 Jul 2026**. Update this file directly as orders land — don't let it go stale like the
old BOM markers did.

Legend: **H** = in hand · **O (date)** = ordered, expected that date · **T** = to order · **L** = to order,
local store only (not worth an online search, per prior sourcing attempts)

---

## 1. Compute, comms, core
| Item | Status | Note |
|---|---|---|
| Arduino UNO Q | **H** ×2 (2GB + 4GB) | Second unit = permanent bench/dev board — never touch the field-bound one once flashed. Genuinely useful given the Aug 8 freeze discipline. |
| Grove LoRa-E5 (IN865) | **H** | — |
| SenseCAP SX1302-4G gateway | **H** — ⚠️ **labeled EU868, architecture requires IN865** | See §Flags below — verify before relying on it. |
| XIAO ESP32S3 + Wio-SX1262 (Meshtastic kit), Wio Tracker L1 | **H**, not in current architecture | Meshtastic ≠ the frozen LoRaWAN IN865 design (ADR 0002). Keep as spares/future-pod hardware; don't let it scope-creep the build. |
| TPA3116D2 amp | **H** | — |
| INMP441 mic | **H** ×2-3 | — |
| INA333 | **H** | — |
| ADS1115 | **H** | Confirmed needed — bench ADC stand-in for the geophone front-end per the build schedule. |
| SM-24 geophone | **H** | — |
| USB hub | **H** | Bridges the IMX462's USB-A UVC connector to the UNO Q's single USB-C port for bench validation (the camera check). Not part of the final field enclosure — a compact USB-C-to-USB-A pigtail is the likely permanent fit once the camera path is proven. |
| Arducam IMX462 | **H** | No stand-in needed — real camera already in hand. |

## 2. Camera + IR
| Item | Status |
|---|---|
| 940nm IR illuminator board | **O — 5 Aug** |
| IR-gate MOSFET | **H** (IRLZ44N, consolidated — see §7) |
| Optical window (acrylic/PC 2-3mm) | **T** — local |

## 3. Geophone burial chain
| Item | Status |
|---|---|
| 2-core shielded cable | **O — 6 Aug** |
| PVC pipe 32mm + end caps | **T** — local |
| SS-304 bolt M10×100 (spike) | **T** — local |
| Araldite epoxy | **T** — local |
| HDPE conduit 20mm | **T** — local |
| MCP6002 (band-pass op-amp) | **O — 4 Aug** |
| PG7 gland (outdoor entry) | **H** ×5 |

## 4. Audio deterrence
| Item | Status |
|---|---|
| DFPlayer Mini | **H** — bench stand-in |
| DFPlayer PRO | **O — 4 Aug** |
| Ahuja SUH-15 horn | **O — ~30-31 Jul** (2-3 days out) |
| Speaker wire | **H** (silicone wire stock covers this) |

## 5. Visual deterrence (LED)
| Item | Status |
|---|---|
| Cool-white 3W LED star ×4 | **O — 5 Aug** |
| Royal-blue 3W LED star ×2 | **O — 2 Aug** |
| XL4015 buck driver ×2 (+1 spare) | **O — 30 Jul** |
| Heatsink puck ×6 | **O — 5 Aug** |
| Thermal adhesive tape | **O — 2 Aug** |
| Steko lens+holder | dropped — not needed |

## 6. Power system — **revised 13 Aug against the Aug 20 deployment deadline**

> **Deadline note, 2 Sept:** the trial date is now **5 Sept** (user-confirmed 1 Sept; see `CONTEXT.md`
> §10). Anything ordered against this section has to land before that date, not before 20 Aug — the
> 20 W panel already missed one deadline by arriving 24 Aug.

Sized 12 Aug against a daily energy budget (baseline-dominated by ADR 0008's 0.42-0.45W MPU-suspend
draw — **a third-party community measurement, not a reading from this board, and describing a suspend
state this codebase does not implement**; see ADR 0008's 2 Sept addendum — for a 12.77Wh/day baseline,
plus event-triggered deterrence load) and real Kerala monsoon-season solar
irradiance, not the annual average. Revised same day to the smallest sizing that's still safe (3-day no-sun
autonomy, 85% DoD). Full calculation, formulas, sensitivity table, and sources:
`hardware/bom/eletect-x-power-budget.xlsx`.

**13 Aug: dropped the "smart" solar charge controller category entirely.** Every purpose-built LiFePO4-aware
unit checked failed real verification: the amiciSmart 10A (₹1,949) has a self-contradicting listing (its own
"Product description" says lead-acid only, contradicting its "About this item" b05 claim), mixed real customer
reviews on 4S packs specifically ("unavailable to charge lifepo4 battery pack of 4S" — verified purchase), and
a separately reported firmware bug (won't auto-resume charging after a low-voltage shutdown — disqualifying
for unattended field hardware on its own). Sparkel's SPSCC-1012LiMPPT (₹2,450, genuinely well-engineered,
IP67, real redundant protection) ships factory-default to **Gel lead-acid**, not Lithium — the "S-Unit" remote
needed to reconfigure it isn't sold anywhere on Sparkel's own site. Victron's Bluetooth-programmable units are
the one category that passed every check but cost ₹6,300+, well outside budget.

**Replacement: XL4015 CC/CV buck module, already in hand (bought 28 Jul).** Set manually to 14.2V output
(conservative vs the 14.6V absorption max, for margin against trimmer-pot drift and less full-charge calendar
stress) with current limit set to ~1-2A, verified with a multimeter before connecting to the pack — fully
inspectable, no firmware to trust. Trade-off, accepted deliberately: no staged bulk/absorption/float charging
and no independent hardware overvoltage backstop from the charge side — the **battery's own BMS becomes the
load-bearing safety component**, see battery row below. This also drops ~₹1,900-2,450 from the original plan.

| Item | Status | Spec pinned by the calc | Real product / decision (13 Aug) |
|---|---|---|---|
| 4S LiFePO4 battery | **O — 14 Aug, ⚠️ delivery risk accepted** | **~6Ah** (design daily need ~19.5Wh incl. 25% margin, x3 days no-sun autonomy, 85% DoD → 5.4Ah, round up). | **[Robu.in Pro-Range IFR 32650 12.8V 6000mAh 3C 4S1P LiFePO4](https://robu.in/product/pro-range-ifr-32650-12-8v-6000mah-3c-4s1p-lifepo4-battery-pack/)**, ₹1,799 (₹1,699 with Robu Points). Ordered 14 Aug accepting the delivery risk (Robu's own checkout quotes **5-7 working days**, realistically Aug 21-24 from this date, worse with their 15-17 Aug "Freedom Sale" — genuinely may miss Aug 20). Picked over ELBOTICS (₹2,399, Prime-confirmed 16 Aug) deliberately: Robu's 75×70mm form factor fits directly inside the main enclosure as originally designed (ELBOTICS's 150×65×100mm brick would've forced a separate base-mounted battery box with its own gland/cable run — one more sealed interface and connector pair, undesirable given the horn already went external per ADR 0011). Also has real engineering advantages once landed: 3C discharge rating gives 5.1x margin over our 3.52A peak load vs. ELBOTICS's 1.7x, and it's the pack the permanent build was already sized around. **Action: call Robu support (1800 266 6123) — confirm the real BMS cutoff-voltage spec (their sheet only says "BMS: Y") and ask if expedited shipping is possible given the date.** If it doesn't land by Aug 19, fall back to deploying whatever's in hand or accept a late start within the 10-day window. |
| Solar charge regulation | **H** — already own one (28 Jul) | Set to CV 14.2V, current-limited ~1-2A, verified by multimeter before connecting battery | XL4015 CC/CV buck (see reasoning above). Buy 1-2 more as spares — [Robu.in LM2596S](https://robu.in/product/lm2596s-dc-dc-buck-converter-power-supply/)-class module or the [Robocraze XL4015 5A, Amazon.in](https://www.amazon.in/Robocraze-Lithium-Battery-Charging-Converter/dp/B07RKH7YVY), ₹259, Prime, 2-day delivery — cheap insurance, arrives well before the 20th. |
| **Solar panel** | **T — source locally this week** | 15W clears the monsoon-derated need theoretically; **20W is the realistic smallest buy** (~2.48x margin), 10W workable at tighter ~1.24x margin if that's what's available | No online 12V panel reliably lands by Aug 20 (10+ alternatives checked, earliest Fri-Sun 22-23 Aug). **Plan: buy a 12V/15-20W panel in person at an electronics/solar shop in Malappuram or Kochi this week** — sidesteps shipping lead time entirely, ~₹700-1,500. The [WAAREE 20W panel already ordered](https://www.amazon.in/WAAREE-polycrystalline-Performance-Warranty-Everyday/dp/B0DJJNS73C) (₹899, lands Mon 24 Aug) is too late for the trial — keep it, don't cancel, it becomes the Phase 2/permanent-build panel. |
| Fuse + holder | **T** — buy locally, not online | **Revised to 6A** (14 Aug) — 5A's margin over the worst-case peak (45.1W) shrinks to just 1.11x at low battery voltage (~10V, 4.51A), below the design's own 1.25x safety convention. 6A restores real margin across the full discharge range at no extra cost. | Every Amazon/Robu inline blade fuse holder checked quotes delivery Aug 21-23. Ubiquitous, cheap part (any electronics/automotive-spares shop) — **source locally**, ~₹100-150. |
| Power switch | **T** — buy locally, reverted 14 Aug (bad online listing spec) | SPST, simple 2-position ON/OFF (not ON-OFF-ON), rated ≥10A/12V DC, panel-mounted | The [Electronic Spices 5PCS rocker switch, Amazon.in](https://www.amazon.in/s?k=12V+DC+toggle+switch+SPST&rh=p_n_delivery_date%3A1) pick was checked against its real spec sheet and rejected: it's actually a **3-position ON-OFF-ON switch** (wrong type — wastes/misuses positions for a simple power cutoff), and its "10 Amps" rating is paired only with "250 Volts," reading as an AC rating with no stated 12V DC figure. **Source locally instead** — ask for a simple SPST toggle/rocker switch, 2-position ON/OFF, rated ≥10A at 12V DC (any electronics or automotive-spares shop stocks this, ~₹30-100). Lets you physically confirm position count and DC rating before buying, which online listing text has twice failed to state clearly. Panel-mount via a cut hole in the enclosure wall (rocker style) or drilled hole + nut (toggle style); seal with a thin bead of silicone around the mounting point either way. Wire: battery+ → fuse → switch → WAGO splice point → branches. |
| USB-C→USB-A adapter (camera) | **O — 15 Aug** | Passive adapter only — board sources camera power itself via VBUS back-drive, see Buck audit below | **[Amkette USB 3.0 Type-C Male to USB-A Female OTG Adapter, Amazon.in](https://www.amazon.in/s?k=USB+C+male+to+USB+A+female+OTG+adapter)** — ₹99, 4.4★ (773 reviews), 400+ bought in past month, delivers tomorrow (15 Aug). Picked over the AGARO/Portronics/Ambrane alternatives specifically because its title states the orientation unambiguously ("Type-C **Male** to USB-A **Female**") — most competing listings phrase this ambiguously ("Type C Female to USB Male"), which is backwards-sounding for our use case and risks ordering the wrong orientation. **For resilience: don't let it hang loose on the port** — zip-tie or hot-glue-dab the adapter body to a fixed point near the port so there's no cantilever stress on the connector under vibration. |
| VIN connection (board-side) | **T** — reverted 14 Aug on cost, jumper + hot glue instead of screw shield | VIN is a through-hole pin on the standard shield-style power header — don't solder wire directly to the board | **Female-to-female jumper wires (already have spare stock/cheap to add) + hot glue for strain relief**, not the ₹282 screw shield. Push the jumper socket fully onto the VIN and GND pins, verify a solid connection with a multimeter, then dab hot glue over the joint to lock it in place mechanically — prevents the connector working loose from vibration without paying for a dedicated part. Real trade-off, accepted for this trial: hot glue secures the wire's *position*, not the *contact quality* at the pin itself, the way a screw terminal's physical clamp does — genuinely fine for a 10-day run, worth upgrading to the screw shield for Phase 2's permanent build where the connection needs to survive years, not days. |
| Separate BMS | not needed — battery's BMS confirmed via label + listing | — | — |
| Load-switch MOSFETs | **H** (IRLZ44N, see §7) | — | — |
| Supercap (optional) | skip for now — revisit only if bench testing shows a brownout on deterrence burst | — | — |
| VIN wiring (silicone wire + XT30) | **H** — XT30UD pair ×2 already in hand from the Robu order | — | — |
| Buck converters (TPA3116D2/IR illuminator insurance) | **O — 14 Aug** — bundled into Robu order #3636219 with the battery | Only needed if either board's real input-voltage tolerance falls below the LiFePO4 pack's 14.6V absorption peak (open verification item, see below) | [Robocraze XL4015, Amazon.in](https://www.amazon.in/Robocraze-Lithium-Battery-Charging-Converter/dp/B07RKH7YVY), ₹259 each, Prime — same part as the solar-charging module, buy extras in one order. |
| Bench charger (optional, no longer required) | dropped — the XL4015 solar-charging path covers initial charge-up too | — | Robu's "Battery Charger 4S LiFePO4 -14.5V 1A" (₹700) is no longer needed unless a bench-only backup charge path is wanted. |

**Aug 20 deadline — decided 14 Aug.** This is a 10-day field trial (deploy, retrieve, review footage), not
yet the permanent install, which changes the risk calculus on both remaining items:
1. **Battery: ordered from Robu 14 Aug, accepting the delivery-timing risk** (see row above) — chosen for the
   compact form factor and discharge margin over the delivery-certain but bulkier/tighter-margin ELBOTICS
   alternative. A 6Ah pack alone, no solar, covers ~3.3 days at the design 85% DoD (65.3Wh usable ÷ 19.47Wh/day
   design load) — not the full 10 days by itself, which is exactly why the panel below still matters.
2. **Solar panel: source locally in Malappuram/Kochi this week** — the actual fix for continuous 10-day
   coverage, since no online 12V panel option lands in time. This is now the primary plan, not a fallback.

**If either slips past Aug 19:** deploy on whatever's in hand and accept partial coverage (battery-only ≈3-4
days of the 10, or delayed start) rather than blocking the whole trial — no additional cost either way.

**Revised total, power block only:** ≈₹2,600-3,450 (battery ₹1,799 + local panel ₹700-1,500 + fuse/holder
~₹100-150 local), not counting the already-sunk WAAREE panel (₹899, held for Phase 2) or the optional spare
XL4015 bucks (₹259-518, only if the TPA3116D2/IR illuminator verification below calls for them) — the cheapest
version of this plan yet, versus the original ₹5,994.

**Buck/regulation audit (13 Aug), all subsystems:**
| Subsystem | Needs a buck? | Why |
|---|---|---|
| LEDs (cool-white/royal-blue) | No — already covered | XL4015 buck driver ×2 already sourced (§3, ordered 30 Jul) |
| UNO Q | No | Confirmed via official Arduino power spec — VIN accepts 7-24V DC, onboard LMR51440 bucks to 5V internally |
| Camera (Arducam IMX462) | No | Powered off USB-C, board-regulated |
| DFPlayer PRO, INA333, ADS1115, LoRa-E5, INMP441, BME280/MPU-6050 (if used) | No, presumed | All draw from the tray's own regulated rails off the UNO Q/perfboard, not directly off the raw battery bus — not yet re-verified against each individual datasheet's absolute max input, worth a quick pass once the tray is populated but not expected to be an issue |
| **TPA3116D2 amp (XH-M543 120W board)** | **Resolved 14 Aug — no buck needed** | Listing spec: Operating Voltage Range 12-24V DC, usage note tolerates DC12V-26V on the input terminal. 14.6V absorption peak sits comfortably inside this range (1.64x margin to the 24V rated max). Wire straight to the battery bus. |
| **940nm IR illuminator board (VISTORA 48-LED, ASIN B0H2DQ9DVK, already purchased 28 Jul)** | **Resolved 14 Aug — buck IS needed** | Listing states a single fixed **Input Voltage: DC12V** (not a range), 300mA draw. The 14.6V absorption peak exceeds this by ~22% — real overvoltage risk to a board with no stated input tolerance margin. **Use one spare XL4015 buck inline, set to ~12V**, ahead of this board specifically. |

Both open items now resolved with real listing data — one spare buck is genuinely needed (IR illuminator),
the amp is fine wired directly to the battery bus. Only need to buy 1 spare XL4015 (₹259), not 2.

## 7. Passives & protection
| Item | Status |
|---|---|
| Resistor kit | **H** |
| Cap kit | **H** |
| 0.68µF film cap ×2 | **O — 30 Jul** |
| 1N4148 ×4 | **H** |
| P6KE18/24CA TVS ×2 | **O — 2 Aug** |
| P6KE6.8CA TVS ×3 | **O — 15 Aug** — Robu, exact part match found, no longer local-only |
| SB5100 Schottky ×1 | **O — 15 Aug** — Robu, exact part match found, no longer local-only |
| IRLZ44N MOSFET | **H** ×5-7 + **O — 14 Aug** top-up bundled into Robu order #3636219 — margin restored, no longer tight |
| LR7843 MOSFET control module | **H** ×1 | Pre-built module, screw terminals — fits the "no PCB fab" constraint better than a bare IRLZ44N for at least one load-switch position. See §Flags. |
| Status LEDs 3mm + 1kΩ | **H** ×2 |

## 8. Environmental sensors
| Item | Status |
|---|---|
| BME280 | **H** |
| MPU-6050 | **H** |
| Electret mic + MAX9814 | **dropped** — see §Flags |

## 9. Enclosure & mechanical
| Item | Status |
|---|---|
| PETG filament 1kg | **H** |
| Silicone O-ring cord | **O — 15 Aug** — SOMA, onlyscrews |
| e-PTFE vent | **O — 4 Aug** |
| SS-304 bracket/U-bolt (main enclosure pole mount) | **O — 15 Aug** — Bectro pole clamp |
| SS-304 bracket/U-bolt (horn pole mount) | **O — 15 Aug** — second Bectro clamp, same part, reused per ADR 0011 horn split |
| PG7/PG9 glands | **H** ×5 each |
| Brass heat-set inserts (onlyscrews) | **O — 15 Aug** | M3-only, "3D Printing" slant-knurled line. Qty 10 each: [M3x4mm](https://onlyscrews.in/products/m3-x-4mm-3d-printing-brass-threaded-inserts-dia-3mm-length-4mm) ₹4.40, [M3x5mm](https://onlyscrews.in/products/m3-x-5mm-3d-printing-brass-threaded-inserts-dia-3mm-length-5mm) ₹4.60, [M3x6mm](https://onlyscrews.in/products/m3-x-6mm-3d-printing-brass-threaded-inserts-dia-3mm-length-6mm) ₹4.80 — ~₹138 for 30 pieces. |
| SS-304 screws (onlyscrews) | **O — 15 Aug** | 1x [M3 Allen Button Head SS304 Assorted Box](https://onlyscrews.in/products/m3-allen-button-head-ss304-assorted-box) (₹240) + individual top-up **M3×8/10/12mm ×15 each** (~₹96) — total ~₹336. |
| VHB double-sided mounting tape (onlyscrews) | **O — 15 Aug** | 3M VHB, transparent 4910 variant for clean bond line — mounts components without screws where a boss isn't practical. |
| M3 standoff spacers (Robu) | **O — 15 Aug** | M3×15mm nylon + M3×5mm brass hex — perfboard solder-joint clearance, camera/IR window offset, UNO Q underside clearance. |
| Desiccant packs | **O — 30 Jul** |

## Already in hand, off the original checklist (Robu wire/connector order)
16AWG silicone wire, 22AWG 2-core, 18AWG PTFE (red+black), 26AWG 4-core, 26AWG 3-core, 26AWG 2-core,
26AWG 5-colour kit, XT30UD pair ×2, JST XH 2/4/6-pin sets, WAGO lever splice connectors (2/3/5-way),
GRM155 0402 SMD 2.2µF cap ×3 (SMD — bench reference only, not usable given no-PCB-fab constraint, low
stakes either way), PG7/PG9 glands (additional stock), LR7843 module.

---

## Flags — need a decision, not just a status

1. **LoRa gateway region mismatch.** CONTEXT.md and the frozen architecture specify **IN865**
   (868MHz is illegal to transmit on in India). The SenseCAP gateway in hand is labeled **EU868**.
   IN865's channel plan (865.0625-867.9MHz) sits inside EU868's typical RF front-end passband
   (863-870MHz), so the hardware may well work once ChirpStack is configured with the IN865 region
   profile — SenseCAP's SX1302 gateways are often software-region-selectable within their filter's
   range — but "may well work" isn't good enough to discover on field-test day. **Action: power it up,
   set the ChirpStack region profile to IN865, and run a real join test with the Grove E5 this week** —
   this is cheap to check now and expensive to find out wrong on Aug 9-14.
2. **INMP441 vs. MAX9814 — good catch, dropping MAX9814.** They weren't redundant purchases of the same
   thing: INMP441 (I2S digital) is the architecture's one acoustic-corroboration sensor (CONTEXT.md §3);
   MAX9814 was listed as an *optional* second, analog, MCU-native mic for a lighter-weight always-on
   listen path. You already have 2-3 INMP441 units and it's marked optional in the original BOM for a
   reason — one sensor doing the job cleanly beats two doing it redundantly (CONTEXT.md §7, "reject
   gimmicks"). Dropped — removed from §8 above, no purchase needed.

   > **Correction, 2026-09-30.** The drop stands as a purchasing decision, but the reasoning above is
   > wrong and later ADRs contradict it, so it should not be cited as justification.
   >
   > The two mics were **not** redundant.
   > [ADR 0006](../../docs/decisions/0006-acoustic-gunshot-gate-and-classifier-split.md) establishes
   > that the MAX9814's role was a binary always-on wake comparator running at STOP-mode power — a
   > different function from the corroboration/classification job the INMP441 does, and one the
   > INMP441 cannot perform because I2S capture does not run in STOP mode. "One sensor doing the job"
   > assumed a single job; there were two.
   >
   > The premise has since failed outright.
   > [ADR 0028](../../docs/decisions/0028-acoustic-capture-moves-to-the-mpu-usb-microphone.md)
   > (accepted 2026-09-29) found the INMP441 path unbuildable on the UNO Q — the prebuilt loader's
   > devicetree never clocks SAI1, so the peripheral the surviving sensor needed is unreachable from a
   > sketch. Acoustic capture moved to the MPU as a USB microphone. The MCU therefore ended up with
   > **neither** mic, which is the outcome this flag was reasoning its way *out* of.
   >
   > Re-buying the MAX9814 is deferred, not rejected; it remains the only design that delivers
   > always-on gunshot detection. Tracked in `docs/KNOWN_GAPS.md`.
3. **IRLZ44N quantity is tight (5-7 in hand vs. ~6-7 needed), not comfortably spare.** Two ways to close
   the gap without a new order: use the **LR7843 module** you already have for one of the load-switch
   positions (camera or IR rail — it's a pre-built screw-terminal switch module, which is a better fit
   for the "no PCB fab" constraint than hand-wiring another bare IRLZ44N with gate/pulldown resistors
   anyway), or add a couple more IRLZ44N to whatever's next Robu order to restore real spare margin.
4. **Battery purchase resolves two BOM lines at once** — buying a pack with integrated BMS (as already
   recommended earlier in this file) means §6's "Separate BMS" line disappears entirely; don't shop for
   it separately.

## Priority order for what's still unordered

1. **Order the power system today.** Battery + MPPT + panel + fuse are the only block with zero orders
   placed, they're the longest remaining lead-time item, and Day "Mon 3 Aug" in `BUILD_BLUEPRINT_AUG8.md`
   already assumes power is in hand and wired by then. Ordering today gives ~5-6 days of shipping slack;
   waiting even a few more days starts eating into that.
2. **Order enclosure hardware this week** (O-ring cord, SS bracket/U-bolt, brass inserts + screws via
   onlyscrews) — needed for the Aug 4-5 enclosure-assembly stage, not urgent today but shouldn't slip
   past this week.
3. **Local-store run this week, no shipping risk either way:** PVC pipe/caps, SS-304 spike, Araldite,
   HDPE conduit, P6KE6.8CA, SB5100, acrylic window — cheap, fast, no reason to wait.

## What this changes about the build schedule

Nothing, structurally — it confirms it. Every item already ordered lands between **30 Jul and 6 Aug**,
which is exactly `BUILD_BLUEPRINT_AUG8.md`'s Stage 2 window ("real hardware lands," Sun 2 – Wed 5 Aug).
None of it blocks Stage 0/1 (today through Sat 1 Aug), since that stage runs entirely on bench stand-ins
you already have in hand: ADS1115+INA333 for the geophone, DFPlayer Mini for audio, and the **real**
IMX462 for vision (no stand-in even needed there — camera's already in hand). Power is the one gap that
needs to close today to keep Stage 2's Aug 3 power-validation task on schedule.

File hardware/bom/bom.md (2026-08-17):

# EleTect X — FINAL Hardware Sourcing (Freeze & Build) — Complete BOM

**All parts India-available (Amazon.in / Robu / local); no imports.** Legend: ✅ HAVE · 🛒 BUY · ⭐ decision note. Prices ≈ July 2026, confirm at cart.

---

## 0. Two decisions locked
- **Camera — LOCKED: `B0CQ4QDCXN` = Arducam IMX462 day/night, auto IR-cut + 940 nm IR, ₹8,680 (Amazon.in).** Only one of the three available that is a proper **active-IR** day/night camera with a top NIR sensor → correct for dark forest. ⚠️ NOT `B0829HZ3Q7` (₹5,932 = OV2710, weak night — budget fallback only, 850 nm). ⚠️ NOT Robu `B0576` IMX662 (₹6,699) — it's a low-light *color* cam with no IR-cut/IR LEDs listed → likely can't do active-IR night; skip unless Robu confirms NoIR. **External IR = 940 nm to match.**
- **Speaker — LOCKED per ADR 0003/0005: Ahuja SUH-15**, flush-mounted into the front face, ₹1,299–3,150. A TOA SC-610 detour (ADR 0004) was reverted (ADR 0005) — it solved the enclosure's "generic box" look with a 3–6x costlier part instead of a form-language fix, which contradicts the project's own cost-effectiveness/scalability principle and meaningfully raises real fleet cost at DFO deployment scale. Compactness/aesthetics are addressed in the enclosure design instead (sentinel two-volume form, visor band, tapered horn cutout).

---

## 1. Compute, comms, core (mostly HAVE)
| Item | Spec | Qty | Status | Source / ₹ |
|---|---|---|---|---|
| Arduino UNO Q | 2 GB | 1 | ✅ HAVE | — |
| LoRa radio | Grove LoRa-E5 (IN865) | 1 | ✅ HAVE | — |
| Amplifier | TPA3116D2 board | 1 | ✅ HAVE | — |
| Mic | INMP441 (I²S) | 1 | ✅ HAVE | — |
| Instrumentation amp | INA333 (module) | 1 | ✅ HAVE ("mic ina") — *confirm it's INA333* | — |
| Geophone | SM-24 10 Hz | 1 | ✅ arriving | — |
| USB hub | — | 1 | ✅ HAVE — **not needed** in frozen design (camera on USB-C direct, audio via DFPlayer). Keep as spare. | — |

---

## 2. Camera + IR subsystem 🛒
| Item | Spec | Qty | ₹ | Source |
|---|---|---|---|---|
| **USB camera** | Arducam **IMX462** day/night USB board — **ASIN B0CQ4QDCXN** (NOT B0829HZ3Q7=OV2710) | 1 (+1 spare rec.) | 6,000–8,680 | Amazon.in (search ASIN **B0CQ4QDCXN**) / Robu / metal-case B0490 |
| **940 nm IR illuminator** | 12 V board, ~45–60° beam, built-in driver (match camera's 940 nm) | 1 | 500–900 | Amazon.in "940nm IR illuminator board 12V" |
| IR-gate MOSFET | Logic-level N-MOSFET (AO3400 or IRLZ44N) module | 1 | 80 | Robu/Amazon.in |
| Optical window | Clear cast acrylic / PC 2–3 mm (cut to size) | 1 | 100–200 | local / Amazon.in |

---

## 3. Geophone burial chain 🛒 (see also passives §7)
| Item | Spec | Qty | ₹ | Source |
|---|---|---|---|---|
| Shielded cable | 2-core shielded (Polycab/Amazon) ~5 m | 1 | 150–400 | [Amazon.in](https://www.amazon.in/Shielded-Signal-transmission-protection-Length/dp/B07DWVY8FT) |
| Capsule | PVC pipe 32 mm + 2 end caps | 1 | 80–150 | local hardware |
| Spike | SS-304 bolt M10 × 100 mm | 1 | 80–150 | Amazon.in / hardware |
| Potting | Araldite Standard (resin+hardener) | 1 | 120–300 | [Amazon.in](https://www.amazon.in/Araldite-Standard-Epoxy-Adhesive-90gm/dp/B08FHBFY27) |
| Conduit | HDPE flexible 20 mm ~3 m | 1 | 100–200 | local / Amazon.in |
| Connector | M12 4-pin IP68 (panel + cable) | 1 | 300–600 | Amazon.in / Zbotic |
| Band-pass op-amp | MCP6002 (dual, low-power) | 1 | 40–90 | Robu/Amazon.in |

---

## 4. Audio deterrence 🛒
| Item | Spec | Qty | ₹ | Source |
|---|---|---|---|---|
| **Audio player** | **DFPlayer PRO** (onboard flash, no SD) | 1 | 500–700 | Robu/Amazon.in *(fallback: DFPlayer Mini + 8 GB microSD)* |
| Horn speaker | **Ahuja SUH-15**, 8 Ω, 15W RMS/23W Max, flush-mounted per ADR 0003 (ADR 0004 TOA SC-610 detour reverted, ADR 0005) | 1 | 1,299–3,150 | Moglix/Amazon.in, or Electrosolutions Trading LLP (Kondotty) |
| Speaker wire | 2-core, ~1 m | 1 | 30 | local |

---

## 5. Visual deterrence 🛒 (India-generic parts; see passives §7)
| Item | Spec | Qty | ₹ | Source |
|---|---|---|---|---|
| White LED | 3 W high-power **cool white** on 20 mm star | 4 | 40 ea | Robu/Amazon.in |
| Blue LED | 3 W **royal blue ~450 nm** on 20 mm star | 2 | 50 ea | Robu/Amazon.in (aquarium/grow LEDs) |
| LED CC driver | PT4115-based buck LED driver (350–700 mA), 12 V in | 2 | 60–120 ea | Robu/Amazon.in |
| LED optics | 20–30° lens + holder for 20 mm star | 6 | 20 ea | Amazon.in |
| LED-gate MOSFET | Logic-level N-MOSFET (AO3400/IRLZ44N) module | 2 | 80 | Robu |
| Small heatsink / Al plate | for LED stars | 1 | 100 | local |

---

## 6. Power system 🛒 (see protection passives §7)

**Pinned by a real daily-energy-budget calculation (12 Aug, revised same day to the smallest safe sizing) —
see `hardware/bom/eletect-x-power-budget.xlsx` for the live, editable model and sources.**

| Item | Spec | Qty | ₹ | Source |
|---|---|---|---|---|
| Battery | **4S LiFePO4 12.8 V, ~6 Ah**, integrated BMS (3-day autonomy, 85% DoD) | 1 | 1,799 | [Robu.in](https://robu.in/product/pro-range-ifr-32650-12-8v-6000mah-3c-4s1p-lifepo4-battery-pack/) — verify BMS/protection before ordering |
| BMS | not needed separately — covered by the battery's integrated BMS | — | — | — |
| Solar charge controller | **PWM/MPPT, explicit LiFePO4 profile**, ≥10 A | 1 | 1,949 | [amiciSmart 10A, Amazon.in](https://www.amazon.in/amiciSmart-Charger-Controller-Intelligent-Regulator/dp/B07T8LBN9J) — In Stock, selectable "b05: LiFePO4" mode confirmed. (Sparkel SPSCC-MPP1220Li was the better spec match but out of stock; Robu's ₹334 unit is lead-acid only — do not use.) |
| Solar panel | **12 V, 20 W** poly | 1 | 899 | [WAAREE, Amazon.in](https://www.amazon.in/WAAREE-polycrystalline-Performance-Warranty-Everyday/dp/B0DJJNS73C) — In Stock (Robu/Loom 20W options confirmed out of stock 13 Aug) |
| Reverse-polarity | Schottky diode **SB5100 (5 A)** *or* P-MOSFET ideal-diode | 1 | 20–60 | Robu |
| Fuse + holder | 5 A blade fuse + inline holder | 1 | 40 | Amazon.in |
| Load-switch MOSFETs | N-MOSFET modules (AO3400/IRLZ44N) for camera/IR/amp/LED rails | 3–4 | 80 ea | Robu |
| Supercap (optional) | 3× 10 F 2.7 V (series) for pulse buffer | 1 set | 200 | Robu *(optional for prototype)* |
| VIN wiring | connect 12.8 V → UNO Q **JANALOG VIN** (7–24 V); silicone wire + XT30/JST | — | 100 | local |

---

## 7. ⭐ PASSIVES & SEMICONDUCTORS — complete list (buy a resistor + cap kit, plus these specifics)

**Easiest: buy an assorted 1/4 W resistor kit + assorted ceramic + film cap kit (₹300–600 total) — it covers most values below.** Then buy these specific parts:

### Resistors (1/4 W, 1% where analog)
| Value | Qty | Use |
|---|---|---|
| 100 Ω | 4 | geophone series protection (×2), MOSFET gate (×2) |
| 1 kΩ | 2 | INA333 gain Rg (×100); spare |
| 3.3 kΩ | 1 | geophone damping (across coil) |
| 10 kΩ | 4 | Vref divider (×2), SDZ pull, spare |
| 33 kΩ | 2 | band-pass low-pass (50 Hz) |
| 100 kΩ | 4 | band-pass high-pass (2 Hz) ×2, MOSFET gate pulldown ×2 |
| 1 MΩ | 2 | geophone bias to Vref |
| 100 kΩ | 2 | (extra pulldowns) |

### Capacitors
| Value | Type | Qty | Use |
|---|---|---|---|
| 0.68 µF | film | 2 | band-pass high-pass (2 Hz) |
| 0.1 µF (100 nF) | film/ceramic | 2 | band-pass low-pass (50 Hz) |
| 100 nF | ceramic | 6 | decoupling (INA333, op-amp, MCUs) |
| 10 µF | electrolytic/ceramic | 4 | Vref filter, rail decoupling |
| 470 µF–1000 µF, 25 V | electrolytic | 2 | amp/LED rail bulk decoupling |

### Diodes / TVS / MOSFETs
| Part | Qty | Use |
|---|---|---|
| **Bidirectional TVS ~5–6 V** (e.g., SMAJ5.0CA / P6SMB6.8CA) | 3 | geophone input surge/ESD (2 to GND + 1 across) |
| **TVS ~18–24 V** (SMBJ18A/SMBJ24A) | 2 | solar + battery input surge |
| **Schottky SB5100 (5 A)** | 1 | reverse-polarity (or P-FET) |
| **AO3400 / IRLZ44N** logic-level N-MOSFET | 6–8 | IR gate, LED gate, load switches (buy a few spare) |
| 1N4148 signal diode | 4 | misc protection/flyback |
| Green/Red status LED (3 mm) + 1 kΩ | 2 | on-board diagnostics (optional) |

---

## 8. Environmental / sensors 🛒
| Item | Spec | Qty | ₹ | Source |
|---|---|---|---|---|
| BME280 | temp/humidity/pressure (I²C/Qwiic) | 1 | 250–400 | Robu/Amazon.in |
| IMU (tamper) | LSM6/ MPU-6050 (I²C) *(optional)* | 1 | 150–300 | Robu |
| Electret mic + preamp | MAX9814 module — MCU always-on gunshot *(optional)* | 1 | 150–250 | Robu |

---

## 9. Enclosure & mechanical 🛒 (print in-house PETG)
| Item | Spec | Qty | ₹ | Source |
|---|---|---|---|---|
| PETG filament | 1 kg (main body + modules) | 1 | 1,000–1,500 | Amazon.in |
| Silicone O-ring cord | 3 mm, ~2 m (gaskets) | 1 | 150 | Amazon.in |
| Pressure vent | e-PTFE / Gore-type vent (or PTFE membrane) | 1 | 150–400 | Amazon.in |
| Mounting bracket | SS-304 bracket / U-bolt (60–110 mm pole) | 1 | 300–600 | Amazon.in / hardware |
| Cable glands | PG7/PG9 IP68 | 4 | 30 ea | Amazon.in |
| Aviation connector | GX16 (expansion port) *(optional, for future pods)* | 1 | 150 | Amazon.in |
| Heat-set inserts | brass M3 ×10, M4 ×4 | 1 set | 200 | Amazon.in |
| Screws | SS-304 M3/M4 assortment + tamper bit | 1 set | 200 | Amazon.in |
| Stainless straps / ties | for pole + cable | few | 150 | local |
| Desiccant packs | silica gel | few | 50 | local |

---

## 10. Cost summary (one prototype node)
| Block | ~₹ |
|---|---|
| Camera + IR | 6,600 |
| Geophone chain | 1,300 |
| Audio deterrence | 1,300–2,300 (Ahuja SUH-15, ADR 0003/0005) |
| Visual deterrence | 900 |
| Power system | 4,500 |
| Passives/semis kit | 700 |
| Environmental | 500–900 |
| Enclosure/mech | 2,600 |
| **Total (already-owned excluded)** | **≈ ₹18,000–20,000** |
*(You already own UNO Q, LoRa, TPA3116, INMP441, INA333, geophone → those aren't re-counted.)*

---

## 11. Order-now checklist (freeze)
1. ☐ **Camera:** Arducam **IMX462 board — ASIN `B0CQ4QDCXN`** (NOT the ₹5,932 `B0829HZ3Q7`, which is OV2710). Try Amazon.in ASIN search → Robu → metal-case B0490 ₹8,680. Match IR to sensor (IMX462→940 nm). *(+1 spare if budget allows.)*
2. ☐ **940 nm IR illuminator board (12 V)** + N-MOSFET.
3. ☐ **DFPlayer PRO** + **8 Ω horn** (Ahuja SUH-15, flush-mount per ADR 0003 — see ADR 0005 for why the TOA SC-610 detour was reverted).
4. ☐ **LEDs:** 4× 3 W white + 2× 3 W royal-blue stars + 2× PT4115 drivers + 6× lenses + MOSFETs.
5. ☐ **Power:** 4S LiFePO4 pack + BMS + MPPT (LiFePO4) + 20 W panel + Schottky + fuse + load-switch MOSFETs.
6. ☐ **Geophone burial:** shielded cable + PVC pipe/caps + SS spike + Araldite + M12 + HDPE conduit + MCP6002.
7. ☐ **Passives:** resistor kit + cap kit + the specific R/C/TVS/MOSFET list in §7.
8. ☐ **Sensors:** BME280 (+ optional IMU, electret mic).
9. ☐ **Enclosure:** PETG + silicone cord + PTFE vent + SS bracket + glands + inserts + screws + acrylic window.
10. ☐ **Confirm** you have: UNO Q, Grove LoRa-E5, TPA3116, INMP441, **INA333** (verify), geophone.

**After these land → freeze the BOM and start building.** Everything is India-sourced, no imports, deadline-safe (camera ships now).

## Sources
[Arducam IMX462 day/night USB **board** B0CQ4QDCXN](https://www.amazon.com/Arducam-Computer-Automatic-Switching-All-Day/dp/B0CQ4QDCXN) · [same on Robu.in](https://robu.in/product/arducam-1080p-day-night-vision-usb-camera-2mp-infrared-webcam-with-automatic-ir-cut-switching-and-ir-leds/) · [Ahuja SUH-15 horn ₹1,299](https://www.moglix.com/ahuja-15w-horn-speaker-suh-15/mp/msnr50n423r251) · [Araldite (Amazon.in)](https://www.amazon.in/Araldite-Standard-Epoxy-Adhesive-90gm/dp/B08FHBFY27) · [shielded 2-core cable (Amazon.in)](https://www.amazon.in/Shielded-Signal-transmission-protection-Length/dp/B07DWVY8FT)

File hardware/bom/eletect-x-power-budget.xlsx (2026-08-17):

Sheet: Assumptions
EleTect X — Power Budget Assumptions
Edit the blue Value cells. Yellow-filled rows are placeholder estimates (no site data yet) — revisit first.
Assumption | Value | Unit | Source / note
Board baseline power (MCU active, MPU deep-suspend) | 0.45 | W | ADR 0008 — real measured 0.42-0.45W @5.1V for this exact use case (continuous sensing, MPU woken only on event). Using worst case.
Sensor front-end + env sensor overhead | 0.08 | W | Estimate: INA333 + MCP6002 dual op-amp + BME280 + MPU-6050 quiescent draw, generous margin (each is sub-mA class).
LoRa idle/heartbeat energy | 0.05 | Wh/day | Estimate: Grove LoRa-E5 (STM32WLE5) TX ~120mA for well under 1s per uplink, ~15 uplinks/day. Effectively negligible either way.
MPU active power (camera streaming + inference) | 6.1 | W | Community-measured Arduino UNO Q camera-inference power draw (forum/review sources, 2026) — see Notes tab for links.
Tier-1 events/day (wake + vision-confirm, no deterrence) | 8 | count/day | PLACEHOLDER — no site-specific detection-rate data yet for this boundary. Adjust once field data exists.
Tier-1 MPU active duration | 90 | s | Estimate: suspend-resume + camera + inference + fusion decision, no deterrence hardware.
Tier-2 events/day (confirmed elephant, full deterrence) | 3 | count/day | PLACEHOLDER — same caveat as Tier-1. This is the single highest-leverage number in this sheet — revisit with real DFO/field data.
Tier-2 MPU active duration | 150 | s | Estimate: resume + camera + inference + fusion + bandit decision + LoRa alert.
Audio deterrence power (during blast) | 18 | W | TPA3116D2 into 8ohm Ahuja SUH-15 horn at ~15W rated acoustic output, ~92% Class-D efficiency (TI datasheet) -> ~16-18W input.
Audio duration per Tier-2 event | 15 | s | Estimate — single deterrence blast.
LED deterrence avg power (irregular strobe, ~55% duty) | 10 | W | Estimate: 18W nominal max string x approx duty cycle for an irregular (not continuous) strobe pattern per CONTEXT.md.
LED duration per Tier-2 event | 45 | s | Estimate.
LED max simultaneous power (all on, full rated current) | 18 | W | 4x3W cool-white + 2x3W royal-blue stars, nominal rated current (BOM section 5). Used for peak/fuse sizing, not daily energy.
IR illuminator power (during capture) | 3 | W | Estimate only — 940nm illuminator board is still on order (status O in procurement tracker). Confirm against real datasheet on arrival.
IR duration per Tier-2 event | 90 | s | Estimate — spans the camera-active portion of the event.
Design margin multiplier | 1.25 | x | 25% margin over the raw calculated total, for estimate uncertainty, cell aging, and temperature derate.
Battery usable depth of discharge (LiFePO4) | 0.85 | fraction | Raised from 0.8 to 0.85 (12 Aug revision, keep the system as small as possible). LiFePO4 tolerates this depth routinely; the node mostly floats near full charge off solar anyway.
No-sun autonomy target | 3 | days | Cut from 4 to 3 days (12 Aug revision, smaller-system request). Recommended floor, not lower - Kerala's monsoon produces genuine multi-week low-generation stretches, and this is a safety system real people rely on. See the sensitivity table on the Battery and Solar Sizing tab.
Battery nominal voltage | 12.8 | V | 4S LiFePO4 (3.2V/cell nominal) — CONTEXT.md section 3, frozen architecture.
Ernakulam/Kochi annual average peak sun hours | 4.6 | h/day | Web search, coastal Kerala solar-generation sources, 2026 — see Notes tab for links. Nearest available proxy to Kothamangalam.
Monsoon GHI derate (Jun-Sep) | 0.3 | fraction | Cited range is 25-35% GHI drop at south Indian coastal sites Jun-Sep. Using the midpoint, biased conservative since Kothamangalam sits nearer the Western Ghats and typically sees heavier monsoon rainfall than coastal Kochi.
System derate (MPPT + wiring + temp + soiling + angle losses) | 0.75 | fraction retained | Standard off-grid solar design derate — i.e. 25% total system loss between panel-rated W and energy actually reaching the battery.
Fuse safety margin over calculated peak load | 1.25 | x | Standard practice — fuse rated above worst-case peak draw, but still well under wire/connector/battery safe limits.

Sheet: Daily Energy (Wh)
EleTect X — Daily Energy Budget
All cells below are formulas driven by the Assumptions tab — change assumptions there, this recalculates.
Item | Calculation | Wh/day
Baseline (24h continuous — reflex layer always on)
Board baseline (MCU active, MPU deep-suspend) | board W x 24h | 10.80
Sensor front-end + env sensor overhead | sensor W x 24h | 1.92
LoRa idle/heartbeat | direct entry | 0.05
Baseline subtotal |  | 12.77
Tier 1 — MPU wake + vision-confirm, no deterrence
Energy per Tier-1 event | MPU active W x (duration s / 3600) | 0.15
Tier-1 daily energy | per-event Wh x events/day | 1.22
Tier 2 — confirmed elephant, full deterrence cycle
MPU active energy per event | MPU active W x (duration s / 3600) | 0.25
Audio deterrence energy per event | audio W x (duration s / 3600) | 0.07
LED deterrence energy per event | LED avg W x (duration s / 3600) | 0.12
IR illuminator energy per event | IR W x (duration s / 3600) | 0.07
Total energy per Tier-2 event |  | 0.53
Tier-2 daily energy | per-event Wh x events/day | 1.59
Event subtotal |  | 2.81
TOTAL daily energy (no margin) |  | 15.58
TOTAL daily energy (design figure, with margin) |  | 19.47

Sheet: Battery & Solar Sizing
EleTect X — Battery, Solar, MPPT, Fuse Sizing
Formula-driven from Daily Energy (Wh) and Assumptions tabs.
Item | Calculation | Value
Battery
Design daily energy | from Daily Energy tab (with margin) | 19.47
Battery capacity needed (Wh) | daily Wh x autonomy days / DoD | 68.72
Battery capacity needed (Ah) | Wh / nominal voltage | 5.37
Recommended battery capacity, rounded up | CEILING to next whole Ah | 6
Solar
Annual average peak sun hours (Kochi/Ernakulam proxy) | from Assumptions | 4.60
Monsoon-derated peak sun hours (design case) | annual PSH x (1 - monsoon derate) | 3.22
Minimum panel wattage needed (theoretical) | daily Wh / (monsoon PSH x system derate) | 8.06
15W panel — monsoon-day harvest | 15 x monsoon PSH x system derate | 36.23
20W panel — monsoon-day harvest | 20 x monsoon PSH x system derate | 48.30
Margin vs need — 15W panel | harvest / design daily need | 1.86x
Margin vs need — 20W panel | harvest / design daily need | 2.48x
Recommended panel: 15W (theoretical) / 20W (realistic purchase)
Reason (revised 12 Aug): 15W clears the monsoon-derated need with about 1.86x margin. In practice, small retail panels are commonly sold in 10W/20W steps, not 15W, so 20W (about 2.48x margin) is the realistic smallest purchasable size - see the Notes tab for a real Robu.in listing.
MPPT controller
Approx. charging current at 20W / battery voltage | panel W / battery V | 1.56
Recommended MPPT continuous rating (min, with margin) | approx current x 1.5 | 2.34
Must be explicitly LiFePO4-profile (absorption ~14.6V, float ~13.6V for 4S) and low quiescent current — a leaky always-on MPPT can itself eat into the small daily budget above.
Fuse (main battery-to-load protection)
Peak instantaneous load (MPU active + audio + LEDs max + IR, worst-case coincident) | sum of peak-draw assumption cells | 45.10
Peak current draw | peak W / battery V | 3.52
Recommended minimum fuse rating | peak current x safety margin | 4.40
Existing BOM fuse spec | hardware/bom/bom.md section 6 | 5
Margin of existing 5A fuse over calculated minimum | 5A / recommended minimum | 1.14x
Autonomy sensitivity (reference only - main figures above use 3-day / 85% DoD)
Scenario | Calculation | Battery (Ah, rounded up)
2 days no-sun (smallest, tighter monsoon risk) | daily Wh x 2 / 0.85 DoD / 12.8V | 4
3 days no-sun - RECOMMENDED | daily Wh x 3 / 0.85 DoD / 12.8V | 6
4 days no-sun (original, more conservative) | daily Wh x 4 / 0.85 DoD / 12.8V | 8
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

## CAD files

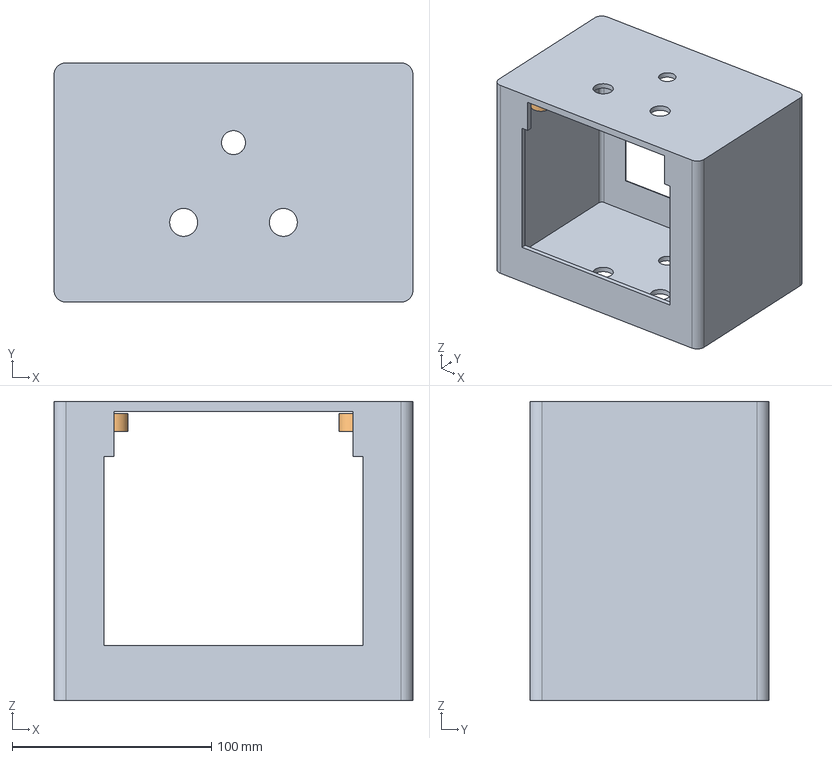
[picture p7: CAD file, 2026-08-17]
hardware/cad/main_enclosure_shell.step
180.0 x 120.0 x 150.0 mm

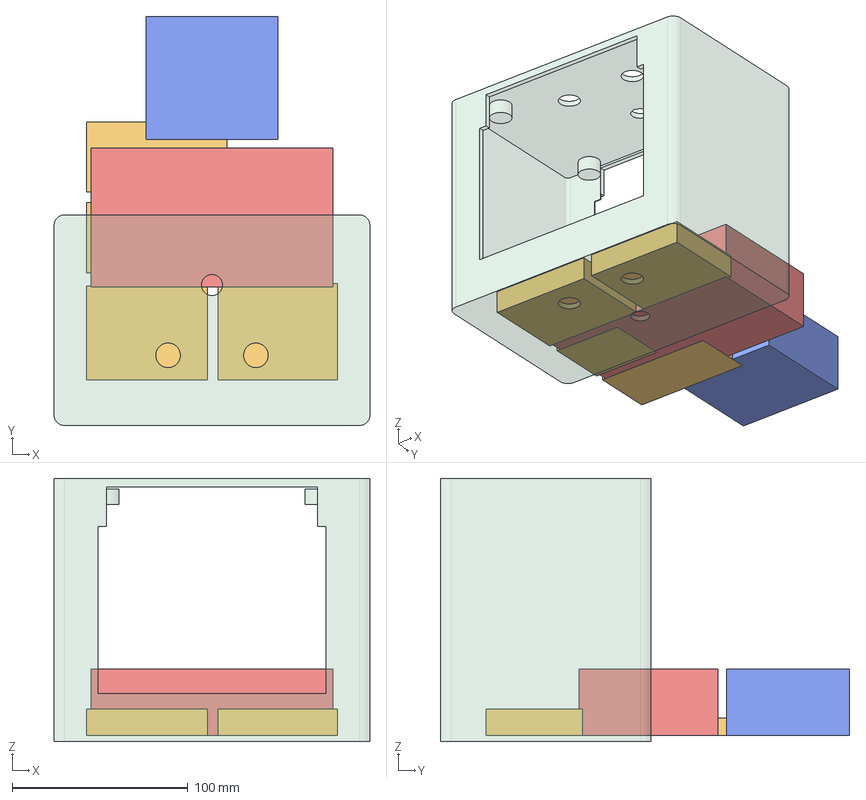
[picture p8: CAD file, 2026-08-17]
hardware/cad/main_enclosure_assembly.step
180.0 x 233.0 x 150.0 mm
main_enclosure_shell
reference_MPPT_controller
reference_battery_pack
reference_UNO_Q
reference_TPA3116D2_amp_board
reference_DFPlayer_PRO
reference_Grove_LoRa-E5
reference_Passives_perfboard_incl._INA333-ADS1115-passives

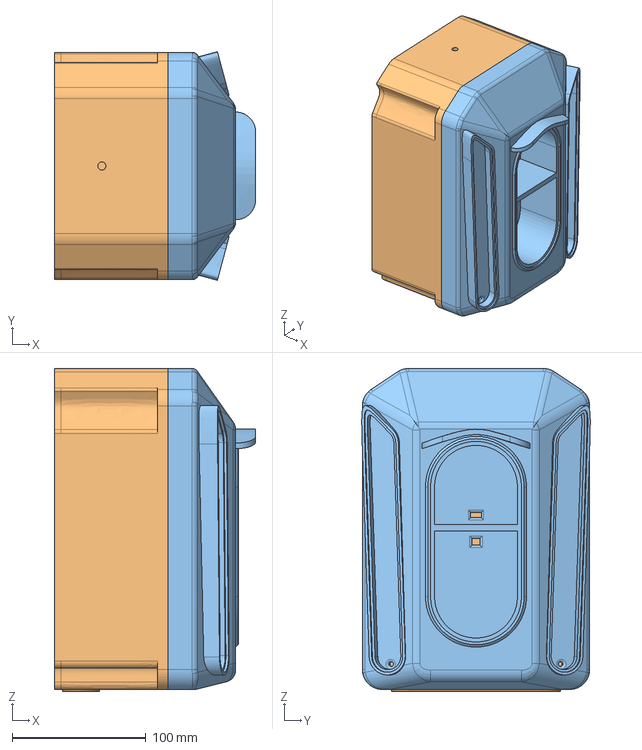
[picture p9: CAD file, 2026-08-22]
hardware/cad/eletect_x_final.step
150.5 x 171.0 x 241.5 mm

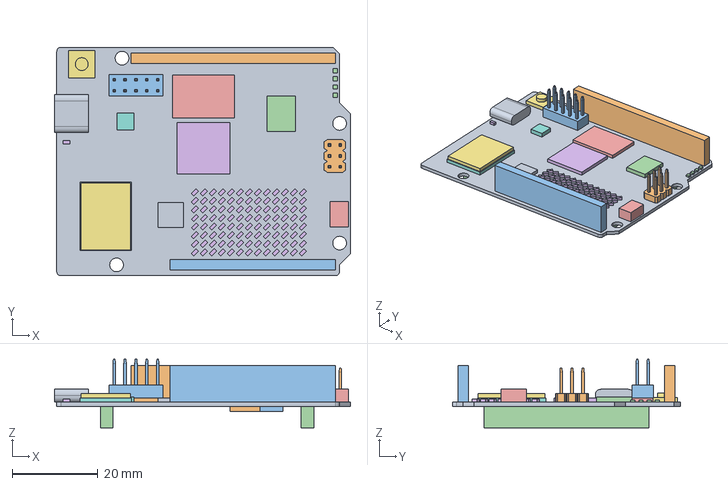
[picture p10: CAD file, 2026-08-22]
hardware/cad/imported_components/UNO Q simplified.stp
69.1 x 53.3 x 16.0 mm

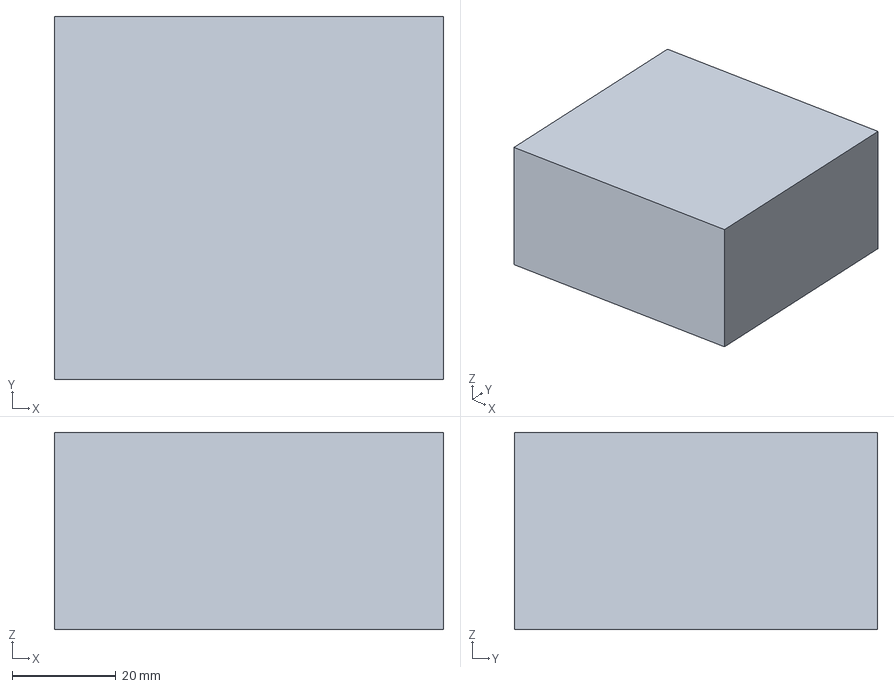
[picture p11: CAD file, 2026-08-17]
hardware/cad/reference_battery_pack.step
75.0 x 70.0 x 38.0 mm

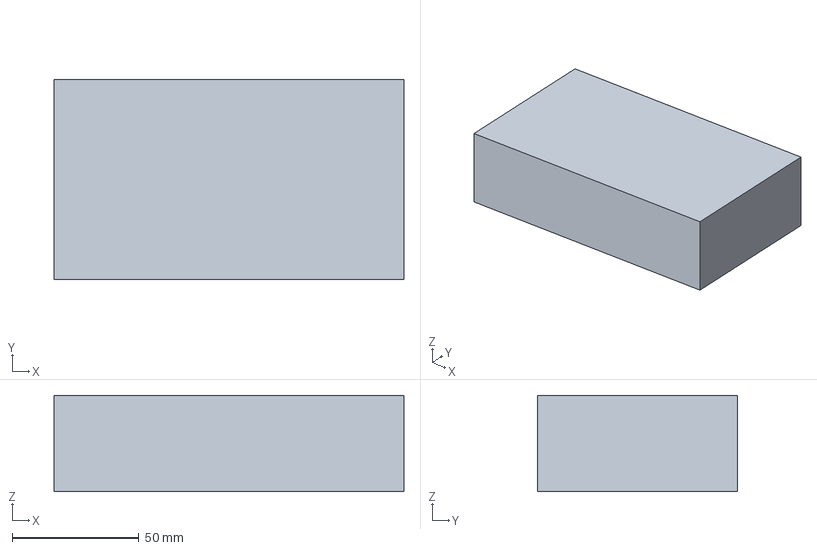
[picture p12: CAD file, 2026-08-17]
hardware/cad/reference_mppt_controller.step
138.0 x 79.0 x 38.0 mm

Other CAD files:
hardware/cad/eletect_x_final.f3z
hardware/cad/main_enclosure_shell.stl

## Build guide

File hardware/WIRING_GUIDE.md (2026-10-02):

# EleTect X — physical wiring guide (bench bring-up, pre-battery)

Written 22 Aug 2026. Covers everything except the battery pack (Robu order #3636219, not yet
landed — see `hardware/bom/procurement-status.md`). Geophone and LoRa are already wired; this
guide is for the five subsystems still at **U** (unwired) in
`hardware/references/UNO_Q_PINOUT_REFERENCE.md`'s wiring-status table: horn, LED white, LED blue,
IR illuminator, and the shared power bus that feeds them.

Every pin assignment and constant below is quoted directly from `device/mcu/src/config.h` (line
numbers as of this writing) and the cited ADRs/BOM — nothing here is invented. Re-check `config.h`
directly if you're reading this more than a session or two after 22 Aug in case a value changed.

## 0. What's already done — don't re-wire this

| Subsystem | Status | Reference |
|---|---|---|
| Geophone (SM-24 → 1kΩ damping → INA333 → ADS1115 → A4/A5 I2C3, `Wire2`) | **W** — corrected 29 Sept 2026 from the field board's `config.h`; D20/D21 are free | `device/mcu/README.md`'s wiring table |
| DFPlayer PRO UART (DFPlayer TX→D0, RX←D1, 115200 AT commands on `Serial1`) | **W** — the field board's horn path; fires in field testing | `hardware/PIN_MAP.md`, ADR 0029 |
| Grove LoRa-E5 | Shares D0/D1 (USART1) with the DFPlayer PRO through a 74HC4053, select on D4; the horn always wins the port (ADR 0029) | `docs/decisions/0029-dfplayer-and-lora-time-share-usart1.md` |
| Camera (Arducam IMX462 → USB hub/adapter → UNO Q USB-C) | Bench-verified, no new wiring needed | `docs/KNOWN_GAPS.md`, build-call 3 |

## 1. Power bus — the part that doesn't need the battery to build

Wire the whole bus now; leave the battery-side leads unterminated (twist-capped or in a spare
WAGO port) until the pack lands. Everything downstream of the bus can be fully built and even
bench-powered from a substitute source today (§1c).

**Topology** (per `hardware/bom/procurement-status.md`'s own power-switch row, "battery+ → fuse →
switch → WAGO splice point → branches"):

```
Battery+ (4S LiFePO4, 12.8V nominal) → 6A blade fuse → SPST switch → WAGO 5-way splice → branches:
  1. UNO Q VIN (7-24VDC input, onboard LMR51440 bucks to 5V — confirmed via official Arduino
     power spec, procurement-status.md §Buck audit)
  2. TPA3116D2 amp DC input (XH-M543 board, rated 12-24VDC per its listing — wired straight to
     the bus, no buck needed, same audit)
  3. LED buck driver #1 input (→ cool-white LED string)
  4. LED buck driver #2 input (→ royal-blue LED string)
  5. IR illuminator's own XL4015 buck input (steps 12.8-14.6V down to the board's fixed 12V
     rating — required, see §4)
Battery− → common ground bus (WAGO or bus bar) → all of the above returns.
```

**Not on this bus: the DFPlayer PRO.** Per its own spec sheet it runs on 3.3-5V, not the 12.8V
actuator bus. Tap its VIN off the UNO Q's 5V pin instead (same rail the LoRa E5's VCC already
uses), GND to common ground. See §3 step 2.

**1a. Fuse and switch.** Both are local-store items per `procurement-status.md` — 6A blade fuse
(revised up from 5A on 14 Aug because 5A's margin over the 45.1W worst-case peak shrinks to 1.11x
at low battery voltage), SPST 2-position ON/OFF rated ≥10A/12V DC. Wire fuse and switch in series
on the **positive** leg only, between battery+ and the WAGO splice — never fuse/switch the ground
return.

**1b. Wire gauge for the bus.** System peak draw is already computed in `procurement-status.md`:
**3.52A at nominal 12.8V, rising to 4.51A at a depleted ~10V pack** (that 45.1W worst-case figure
divided by voltage). Sized against a real automotive 12V ampacity chart (2% voltage-drop
convention, [WiringProducts' automotive wire chart](https://wiringproducts.com/pages/wire-amperage-capacity-chart)):
16AWG carries 5A comfortably out to 11.5ft, 10A out to 5.8ft. Your run inside one small enclosure
is under 1ft in every case, so gauge choice here is about safety margin and connector fit, not
voltage drop.

Use what's already in hand (`procurement-status.md`'s "Already in hand" list) — no new wire
purchase needed:
- **16AWG silicone wire** — main bus: battery+ → fuse → switch → WAGO, and WAGO → each branch's
  first few inches before it steps down to a lighter gauge at the load itself. This is your
  heaviest stock and the right choice for the only run carrying the full system current.
- **18AWG PTFE (red+black)** — branch feeds to the TPA3116D2 amp's DC input and to each XL4015
  buck driver's input side (LED bucks, IR buck) — each of these branches carries at most ~1A,
  18AWG has enormous margin.
- **22AWG 2-core** — buck driver *output* → LED string, and IR buck output → IR board (each ≤0.3A,
  see §4/§5).
- **XT30UD pair** (2 in hand) — good fit for the battery-to-fuse or fuse-to-switch joint if you
  want a disconnectable bench connector there rather than a permanent solder/crimp joint;
  otherwise WAGO levers throughout are simpler and already specified.
- **WAGO lever splice connectors (2/3/5-way, in hand)** — use the 5-way at the main splice point
  exactly as `procurement-status.md` specifies.

**1c. Real battery in hand (22 Aug) — first-use checklist before it touches anything.** The Robu
Pro-Range IFR 32650 12.8V 6000mAh 4S1P LiFePO4 pack has arrived
(`hardware/bom/procurement-status.md`). Before it connects to the bus for the first time:

1. **Multimeter the resting voltage before touching anything else.** A healthy 4S LiFePO4 pack
   rests somewhere in the 12.8-13.6V range depending on state of charge — it should not read near
   0V (dead/miswired BMS) or above ~14.6V (over-charged, do not use). If it reads outside a sane
   range, stop and don't connect it.
2. **Confirm polarity at the XT30 connector before plugging in** — reversed polarity on a LiFePO4
   pack is a real fire risk, not just a "won't work" mistake. The XT30UD pairs already in hand are
   keyed, but verify with the multimeter anyway; don't trust the connector shape alone on a
   first-ever connection.
3. **No fuse/switch yet, and this is now the real pack, not a current-limited bench supply** — a
   short on this bus can deliver far more fault current than a wall adapter ever would, limited
   mainly by the BMS's own trip threshold and the battery's internal resistance, not by anything
   you've wired. Getting the ₹100-150 fuse+switch before this pack goes anywhere near the actuator
   bus is a stronger recommendation now than it was with a bench supply — if a local store is
   reachable before you wire further, that's the highest-leverage five minutes in this bring-up.
   If it genuinely isn't reachable in time: keep every connection brief and supervised, verify each
   new branch with the multimeter before power-on, disconnect the battery between stages rather
   than leaving it hot while you wire the next one, and never leave it connected unattended.
4. **Charging setup (XL4015 set to 14.2V CC/CV) is a separate task from this bring-up** — the
   pack should already carry enough charge to bench-test the actuators directly off it; don't wire
   up the solar/charge path now unless you specifically want to. Keep that XL4015 distinct from
   the two load-side XL4015 bucks (LED, IR) — three total XL4015 modules in this system, easy to
   mix up.

Do **not** substitute the UNO Q's own USB-C port for the 12.8V actuator bus — USB-C powers the
board itself only (5V rail); it isn't wired to backfeed the actuator bus and isn't safe to attempt.

## 2. GPIO control-signal wiring (D2/D3/D4/D5/D6/D7/D8)

These are logic-level signal wires, not power — the UNO Q's own thin jumper wire or the 26AWG
stock in hand is correct here, not the heavier bus gauges above. All pins below are confirmed
5V-tolerant on input per `hardware/references/UNO_Q_PINOUT_REFERENCE.md`'s official warning
("all MCU GPIOs are 3.3V logic and 5V tolerant, except A0 and A1") — relevant below because the
IRLZ44N gate side taps in at 3.3V, not 5V.

| Pin | MCU pin | `config.h` name | Drives |
|---|---|---|---|
| D2 | PB3 | `AUDIO_TRIGGER_PIN` | retired — driven idle-high, not wired. The DFPlayer is driven by UART AT commands on D0/D1 (§3) |
| D4 | PA12 | `UART_SHARE_SELECT_PIN` | 74HC4053 select for the DFPlayer/LoRa USART1 share: LOW = DFPlayer, HIGH = LoRa-E5 (ADR 0029). Plain GPIO — the "USB D+" claim is withdrawn |
| D11 | PB15 | `HORN_AMP_ENABLE_PIN` | IRLZ44N gate switching the XH-M543 `VCC`, active-low (§3). **Field-confirmed** — this is the field board's pin |
| D5 | PA11 | *free — was `LED_WING_LEFT_PIN`* | Free, usable, PWM-capable (TIM1_CH4). The 31 Aug "USB D−, silent no-op" diagnosis is withdrawn (`hardware/PIN_MAP.md` header). |
| D3 | PB0 | `LED_WING_LEFT_PIN` (moved here from D5 on 31 Aug 2026) | IRLZ44N gate, left wing — mixed white+blue LEDs, real 2-wing/2-MOSFET build. PWM-capable (TIM3_CH3); OPAMP2 output shares the pin but is unused here. **Bench-confirmed 31 Aug.** |
| D6 | PB1 | `LED_WING_RIGHT_PIN` (renamed 30 Aug, was `LED_BLUE_PIN`) | IRLZ44N gate, right wing — mixed white+blue LEDs, real 2-wing/2-MOSFET build. **Bench-confirmed 31 Aug.** |
| D8 | PB4 | **planned `LED_BLUE_RIGHT_PIN`** — not yet in `config.h` | IRLZ44N gate, blue LED branch, right wing (§4). PB4 is also JTAG NJTRST — verify it's actually free before assigning. |
| D7 | PB2 | `IR_ILLUMINATOR_PIN` | IRLZ44N (or LR7843 module) gate, IR board (§5). **Bench-confirmed 31 Aug** — `pulse_ir` fired, IMX462 camera-diff showed +99.5 % scene luma on a 500 ms pulse. |

**Left/right wing (D3/D6) and IR (D7) are wired, flashed, and physically fired as of 31 Aug 2026** —
see `HANDOVER.md` "RESUME HERE — 31 Aug, ~14:00". **D8 is still a planned addition, not yet in
firmware — see §4.0.** Don't wire D8 expecting `led.cpp` to drive it; `config.h`/`led.cpp`/`led.h`
need the update first, same one-at-a-time Bridge-registration discipline as every other actuator pin
in this repo.

**Pin lesson (31 Aug 2026) — withdrawn 29 Sept 2026.** It said D4/D5 were the USB D+/D− pair and
unusable; the STM32 on the UNO Q has no USB at all and both are ordinary GPIO (`hardware/PIN_MAP.md`). Clean digital-header
GPIOs confirmed usable: D3 (PB0), D6 (PB1), D7 (PB2), D9 (PB8). D2 (PB3) and D8 (PB4) are JTAG
SWO/NJTRST — usable but verify first.

## 3. Horn: DFPlayer PRO → TPA3116D2 (XH-M543) → Ahuja SUH-15

Per ADR 0003 (single BTL channel, not PBTL) and ADR 0011 (SUH-15 now lives in its own small IP66
housing, off the main enclosure, connected by 2-core speaker wire through a gasketed gland).
Revised 22 Aug against the real DFPlayer PRO (DFR0768) datasheet/schematic and the actual
techtonics XH-M543 board photos — three corrections from the original plan, all verified against
primary sources, not assumed:

1. **DFPlayer PRO power: VIN → UNO Q 5V, GND → common ground.** Its spec sheet states 3.3-5V —
   it does **not** go on the 12.8V actuator bus (see §1's new note). Confirm with a multimeter
   before connecting.
2. **Superseded 29 Sept 2026 — `KEY` is not used.** The DFPlayer PRO is driven with UART AT
   commands on D0/D1 (`Serial1`, 115200, through the 74HC4053: DFPlayer TX → Y0, RX ← X0), which is what lets the
   firmware pick the track and volume per tier. The KEY-pin wiring below is kept for history.
   *Original text:* **D2 (`AUDIO_TRIGGER_PIN`, PB3) → DFPlayer PRO's `KEY` pin, active-low.** This is the DFR0768's
   real pin name — "IO/ADKEY" was the DFPlayer *Mini*'s naming, different hardware. The DF1101S
   chip inside the PRO pulls `KEY` up to its own IO rail through a 22kΩ resistor (idle **high**)
   and reads a direct short to ground as key K1 = Play & Pause (confirmed in the DF1101S
   datasheet §5 and cross-checked against a DFRobot reference schematic for a sibling board using
   the same chip). `horn.cpp` was fixed 22 Aug (commit `493f2fb`) to idle `AUDIO_TRIGGER_PIN` high
   and pulse it low — matches this circuit now. A direct jumper from D2 to `KEY` is correct, no
   resistor needed (K1's own series resistance is 0Ω).
3. **DFPlayer PRO's `DACL` pin → amp's `INL` terminal; DFPlayer `GND` → amp `GND`** (the 3-pin
   `VOL_L | INL GND INR | VOL_R` input block on the XH-M543 board). **Do not use the DFPlayer's
   `L+`/`L-`/`R+`/`R-` pins here** — those are its own built-in speaker-level BTL output, meant to
   drive a bare speaker directly, not to feed another amp's line input; wiring them into `INL`
   would mismatch both signal level and topology. `DACL` is the chip's actual line-level DAC
   output (1Vrms swing per the DF1101S datasheet §3.4) — the correct signal for this path.
4. **No hardware shutdown/mute pin exists on this board.** The techtonics XH-M543 listing (₹289,
   the one actually in hand) and its product photos confirm the only terminals are: power in
   (`VCC`/`GND`), the 3-pin audio input above, two speaker outputs (`L`, `R`), and two volume
   trimpots (`VOL_L`, `VOL_R`). `config.h`'s `HORN_AMP_ENABLE_PIN` comment assumed a `SHUTDOWN`
   pin that this specific board doesn't expose. **Fallback: D11 (`HORN_AMP_ENABLE_PIN`, PB15 — the field board's pin; older text said D4) →
   IRLZ44N gate (or the LR7843 module), switching the amp's `VCC` line** — same 220-330Ω series
   gate resistor + 10kΩ pulldown pattern as §4/§5's LED and IR MOSFETs. This is power-side
   enable/disable instead of an IC mute pin, but functionally the same gate that
   `HORN_AMP_ENABLE_DELAY_MS` (150ms, still an invented placeholder per `docs/KNOWN_GAPS.md`)
   times against.
5. **Amp output (`L+`/`L-` on the XH-M543, the channel wired to `INL`) → Ahuja SUH-15 (8Ω)**, via
   2-core speaker wire through the gasketed gland into the horn's separate housing (ADR 0011).
   16-18AWG stock in hand is fine for the ~1A the amp draws at its software-limited 6-8W output.
6. **Amp `VCC`/`GND` → the IRLZ44N switch from step 4 → power bus** (§1). No buck needed — this
   board's spec (12-24V range, 2×50W at 12V) covers the 12.8-14.6V range with margin.

**Volume control — better news than originally thought.** The XH-M543's `VOL_L` trimpot sits
*after* the DFPlayer in the signal chain, so it's a real physical gain stage independent of
whatever volume the DFPlayer itself is set to — unlike a pure DFPlayer-only setup, you're not
purely at the mercy of an unknown value baked into the module's flash. **Turn `VOL_L` fully
counterclockwise (minimum) before first power-on**, trigger a test play, and bring it up
gradually while listening, rather than assuming any starting position is safe.

## 4. LED deterrence: cool-white + royal-blue via IRLZ44N

**4.0 Redesign decided 22 Aug (Cowork planning session) — supersedes the ×4/×2, 2-channel plan
below wherever it conflicts. Not yet reflected in `config.h`/`led.cpp`/`led.h`.**

Real constraint discovered same night: only 10 heatsink pucks in hand, against a much larger bare-LED
stock. Decision, reasoned from deterrence effectiveness / practicality / power (not from enclosure
CAD, which is not fixed):

- **10 LEDs total, all heatsinked (never run a 3W star bare — real field-reliability risk over a
  multi-day trial): 6 cool-white + 4 royal-blue.** Ratio 1.5:1, not the original BOM's 2:1 — still
  white-leaning (cool-white's phosphor hump overlaps the ~496nm rod peak most large-mammal targets
  use at night better than narrow royal-blue does) while keeping blue meaningfully present (hedges
  the ~30% non-nocturnal encounters, and doubles as spectral-diversity insurance against exact
  photoreceptor-tuning uncertainty).
- **4 independent channels, not 2**: white-left / white-right / blue-left / blue-right. Each color
  still has exactly one buck (2 bucks total, unchanged from the original BOM, already in hand) —
  the buck output splits into two matched parallel branches (left wing, right wing), each gated by
  its own IRLZ44N. White = 3 branches of 2-LEDs-in-series (2 on one wing's switch, 1 on the
  other's — see below); blue = 2 branches of 2-LEDs-in-series (1 per wing). Branches within one
  color are always 2-in-series, sized against the buck's dropout margin at a depleted ~10V pack —
  do not run 3 in series per branch, that's the real ceiling, not an arbitrary one.
- **Why 4 channels, not 2:** the actual evidence-backed deterrence lever is unpredictability, not
  raw brightness — real field literature on flashing-light deterrents (coyote/sheep strobe-siren
  trials, FoxLights, and a directly-relevant finding that elk/deer habituate fast to *stationary*
  deterrents) says varying pattern and color prevents habituation; a static "both wings, both
  colors, every time" burst does not. 4 independent channels let `led.cpp`/the bandit layer
  actually alternate side and color across triggers instead of firing identically every time.
  `ALERT_LED_PATTERN_ID` (already a placeholder in the MPU cognition layer, currently unwired) is
  the natural hook for this — implementing real pattern logic there is higher-value than any
  further LED-count increase.
- **Power/fuse check, real and not yet done — do this before wiring 10 LEDs:** 10 LEDs at ~2.24W
  each (700mA × ~3.2V typical for a 3W star) is ~22.4W if every LED fired simultaneously, versus
  ~13.4W for the original 6-LED plan the existing 6A fuse was sized against
  (`hardware/bom/procurement-status.md`'s 45.1W worst-case-peak / 1.11x-margin calculation). That's
  roughly +9W on top of the system's worst-case simultaneous peak (horn + LED + IR all firing at
  the top deterrence tier). **Re-run that worst-case-peak arithmetic with 10 LEDs before wiring
  them** and confirm the 6A fuse still clears the project's own 1.25x safety convention at a
  depleted pack — if not, it's a cheap fuse-rating bump, not a redesign, but it must be checked,
  not assumed.
- **Firmware work needed before this is real** (one-at-a-time Bridge discipline as always): the
  current 2-wing build uses **D3** (`LED_WING_LEFT_PIN`, moved off D5 on
  31 Aug — D5 is USB D−) and **D6** (`LED_WING_RIGHT_PIN`). A 4-channel expansion would need two
  more clean GPIOs — **D3 is no longer available**, so pick from D9 (PB8) and one JTAG-shared pin
  (D2/PB3 SWO or D8/PB4 NJTRST) after verifying it's free — then extend `led_channel` in `led.h`
  from `{kWingLeft, kWingRight}` to 4 values (or a color×side pair), extend `led.cpp`'s
  `channel_state` array from 2 to 4 instances, and update `bridge_handlers.cpp`/`schema.md`'s
  `drive_led` channel field to address 4 channels. None of this is wired live yet — same
  commented-out-`Bridge.provide()` discipline applies to any new registration.

Everything below (buck sizing, MOSFET gate pattern, wire gauge) is unchanged and still correct —
only the channel count and per-branch LED count change. Read it per-branch: wherever it says "the
LED string," that's now "one 2-LED-in-series branch," repeated 3× for white and 2× for blue.

**Per wing** (repeat for the left and right wing, using D3/D6 respectively — D3 replaced D5 on
31 Aug 2026 because D5/PA11 is USB_OTG_FS D−):

1. **XL4015 buck driver, battery bus → LED string.** Set the buck's output voltage/current to
   match the LED string's forward-voltage/current spec (wire the LEDs in the series/parallel
   configuration your buck driver's rated output current supports — a 3W LED typically runs
   ~700mA at ~3.2-3.4V forward voltage; check the actual star datasheet you received before
   setting the trimmer, since "3W" alone doesn't fix the exact Vf/If). Mount each LED star on a
   heatsink puck with thermal adhesive tape — these get genuinely warm at 700mA and the puck is
   there for a reason, don't skip it.
2. **IRLZ44N as a low-side switch between the LED string's return and ground.** IRLZ44N is a real
   logic-level MOSFET — datasheet-confirmed gate threshold `Vgs(th)` ≈1-2V, and it's specifically
   designed for direct low-voltage gate drive (down to and below 5V) rather than the ~10V a
   standard power MOSFET needs. At the UNO Q's 3.3V GPIO drive it's fully in logic-level territory
   and will switch cleanly at these LED currents (≤~1.4A per channel across 2 LEDs) — `Rds(on)`
   at 3.3-5V gate drive is in the tens-of-milliohms range per the datasheet, negligible heating at
   this current. ([IRLZ44N datasheet, thierry-lequeu.fr mirror](https://www.thierry-lequeu.fr/data/IRLZ44N.pdf))
   Wiring: LED string cathode → MOSFET drain; MOSFET source → ground bus; MOSFET gate ← D3 (or D6)
   through a **220-330Ω series gate resistor** (standard practice, limits inrush into the gate
   capacitance — not in the BOM by name but any resistor from the existing kit in that range
   works) and a **10kΩ pulldown resistor from gate to source** (holds the LED firmly off during
   MCU boot/reset, before `led_init()` has run — without this, an undriven gate can float and
   flicker the LED on briefly at power-up).
3. **Buck driver output → LED string**: 22AWG 2-core is right for this run (≤1.4A per channel,
   well inside 22AWG's margin over a short in-enclosure run).

## 5. IR illuminator: 940nm board via its own XL4015 buck

Per the BOM's flagged finding (`procurement-status.md` §6 Buck/regulation audit): the VISTORA
48-LED IR board (ASIN B0H2DQ9DVK) states a **single fixed Input Voltage: DC12V** (not a range),
drawing 300mA — the battery bus's 14.6V absorption peak exceeds this by ~22%, a real overvoltage
risk to a board with no stated input tolerance margin. This is why one of the spare XL4015 bucks
is earmarked specifically for this board, set to output ~12V.

1. **Battery bus → dedicated XL4015 buck (set to 12V output, verified by multimeter before
   connecting the IR board)** → IR board's 12V input.
2. **D7 (`IR_ILLUMINATOR_PIN`, PB2) → gate of an IRLZ44N low-side switch** on the IR board's
   ground return, same gate-resistor + pulldown pattern as §4 — or use the **LR7843 module**
   already in hand (pre-built screw-terminal MOSFET switch) here instead of a bare IRLZ44N, since
   `procurement-status.md`'s own Flag #3 suggests this exact position as the best fit for it (it's
   a better match for the "no PCB fab" constraint than hand-wiring another bare IRLZ44N).
3. `IR_PULSE_MAX_MS` is 500ms with a 5s minimum interval (config.h lines 394-398) — sized to keep
   duty under 10% at max pulse width specifically to stay inside the gate MOSFET's thermal limit,
   per the comment in config.h. Nothing to wire differently for this, just worth knowing why those
   numbers are what they are before you consider changing them.

## 6. Before first power-on — checklist

1. Multimeter-verify the XL4015 buck outputs (main charge-path buck if wired, LED bucks, IR buck)
   **with no load connected**, before connecting anything downstream — this is the same discipline
   `procurement-status.md` already specifies for the charge-side XL4015.
2. Confirm fuse and switch are both in the positive leg only, ground bus is common and unfused.
3. Turn the XH-M543's `VOL_L` trimpot to minimum before the amp's MOSFET enable (D11/IRLZ44N) is
   ever switched on (§3) — it's the one real physical volume control in this signal path.
4. Confirm every IRLZ44N (or LR7843) gate has its pulldown resistor before power-on — an
   undriven/floating gate on a logic-level MOSFET can partially turn on unpredictably. This now
   includes the horn's amp-enable MOSFET (§3 step 4), not just the LED/IR channels.
5. Once everything above is wired and the bench power source (§1c) is connected: flash with
   `FIRE_TEST_HARNESS 1` (same procedure as the 22 Aug bare-board session,
   `docs/eletect-x-applab-notes.md`) and test each actuator with the `1`/`2`/`3`/`4` console
   commands — this is the fastest path from "wired" to "confirmed working," no new firmware
   needed. Watch/listen for each fire this time, since last session only had the console ack to
   go on.
6. Update `hardware/references/UNO_Q_PINOUT_REFERENCE.md`'s wiring-status table (D2/D4/D5/D6/D7
   from **U** to **W**) as each one is confirmed — keep that table current, same discipline it
   already documents for itself.

Sources: [IRLZ44N datasheet (thierry-lequeu.fr mirror)](https://www.thierry-lequeu.fr/data/IRLZ44N.pdf), [Automotive wire amperage capacity chart, WiringProducts](https://wiringproducts.com/pages/wire-amperage-capacity-chart)

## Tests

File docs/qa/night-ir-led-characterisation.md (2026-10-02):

# Night characterisation: external IR illuminator, LED wings, and camera interaction

**Rig:** production hardware, Kothamangalam backyard. Arduino UNO Q (STM32U585 MCU + Linux MPU),
Arducam IMX462 USB UVC camera, external 850 nm IR illuminator on the MCU's IR MOSFET, dual LED
wings per ADR 0014 §E.
**Dates:** 1–2 September 2026. Findings 1–3 measured 18:27–18:50 UTC (23:57–00:20 IST); the
Finding 4 exposure/IR battery ran ≈ 00:20–01:25 IST 2 Sept; a dawn-transition soak ran ≈ 02:17–08:29
IST and captured the night→day crossover before a board reboot ended it. Overcast, no moon, no
artificial light in frame.
**Board identity:** `boot_id 6b2c727a-af0d-4517-a6c7-a8069da92a64`, container `eletect-x-main-1`
restart count 0, held unchanged through every measurement in Findings 1–4 and the full dawn
transition. The board then rebooted spontaneously at ≈ 08:27 IST (64 s, self-recovered, new
`boot_id 2c601696-8ce6-463d-917b-6da275008c34`) — after all measurement was done; see the Appendix.
No reflash at any point.

Harness: `night_char.py` on the MPU, host V4L2 path (not the container camera path — see
[Method](#method)). Raw frames and per-run JSON under `/home/arduino/vdiff/nightchar/`. Every
number below is reproduced in this document so it survives the board being reimaged.

## Why this was measured

Two questions blocked further deterrence work:

1. **Does the external IR illuminator actually buy us anything at night, and at what range?**
   ADR 0009 assumed it did. Nobody had measured it on the real optic, in the real scene, at the
   real standoff distances. Without a number there was no basis for deciding when to spend the
   MOSFET duty budget and the battery on it — which is exactly the decision ADR 0019 has to make.
2. **Do our own LED wings blind our own camera while they fire?** If the strobe washes out the
   frame, then detection and deterrence must be serialised (deter, wait, re-detect), which costs
   seconds on every encounter and makes "did it work?" unanswerable in real time. If it does not,
   they can overlap.

## Scene geometry and metrics

The frame is scored whole and in four horizontal bands, top of frame being furthest away:

| Band | Frame rows | What it covers in this yard |
|---|---|---|
| `far` | 0–30% | Beyond the treeline, background |
| `treeline` | 30–55% | The vegetation edge — **where an animal first becomes visible** |
| `mid` | 55–78% | Open ground |
| `near` | 78–100% | Immediate foreground, within a few metres of the unit |

Per band: mean **luma** (0–255), **contrast** (luma std), mean HSV **saturation**, **sharpness**
(variance of the Laplacian — a standard focus/detail measure, higher is more resolved detail), and
**clip_hi** (fraction of pixels above 250, i.e. blown out).

Sharpness is the metric that matters most here. Luma only says the scene got brighter; a detector
needs recoverable *structure*. A rise in Laplacian variance means real edges appeared, not just
that the histogram shifted.

## Method

Three things had to be got right before any of these numbers were trustworthy. All three cost real
time to find, so they are recorded here.

**Exposure had to be locked.** The camera's automatic gain control reacts to the IR pulse within a
frame or two and pulls sensor gain back down, holding output luma roughly constant and hiding the
illuminator's effect. The first sweep, run on auto-exposure, measured a full-frame delta of only
**+3.2%** (lit 126.30 vs dark 122.42) with sharpness going *down* by 5.0 — a result that, taken at
face value, would have said the illuminator does nothing. It is an artefact of AGC. All subsequent
runs set `CAP_PROP_AUTO_EXPOSURE = 1` (manual) then `CAP_PROP_EXPOSURE` to a fixed value, and the
readback was verified on every camera open. Note that the host V4L2 path accepts exposure writes;
the container's camera path does not, and sits frozen at 156.

**The capture window had to be much longer than the pulse.** `pulse_ir()` is fired through a
`docker exec`, which cold-starts in 1–3 s, while the pulse itself is only 500 ms. An early version
of the harness captured for 3 s from the moment the fire call was *issued*, so the pulse routinely
landed at or past the end of the window: one run yielded **0 lit frames out of 30**, another
yielded **1**. The window was extended to 11.5 s.

**Photometry had to leave the hot loop.** Running `photometrics()` and `infer()` inline throttled
capture to 5–8 frames per window. The loop was reduced to `cap.read()` plus a cheap grayscale mean,
with all photometry, inference and JPEG writing moved to post-processing, and lit/dark
classification done afterwards against a per-cycle reference (a frame counts as *lit* if its
grayscale mean exceeds that cycle's own 6-frame pre-fire reference by more than 2.0). Lit-frame
yield went from 1 to ~83 per run.

Each sweep is 8 cycles of a single 500 ms pulse, spaced to respect the firmware's 5 s minimum IR
interval.

## Baselines — the unlit scene

Six frames each, LED off, IR off, night.

| Run | Exposure | Full luma (sd) | Sat | Sharp | far | treeline | near | Vision boxes |
|---|---|---|---|---|---|---|---|---|
| `base_auto` | auto | 132.90 (0.66) | **0.000** | 85.9 | 125.68 | 136.79 | 134.39 | 0 |
| `base_lock250` | 250 | 119.81 (0.67) | **0.000** | 86.2 | 112.86 | 123.49 | 121.28 | 0 |
| `base_lock50` | 50 | 29.82 (0.28) | **0.000** | 79.2 | 26.51 | 32.58 | 29.66 | 0 |

Two things to take from this.

**Mean HSV saturation is exactly 0.000 at night, on every band, in every baseline.** The IMX462
swings its mechanical IR-cut filter out once the scene is dark enough and the image goes genuinely
monochrome. A daylight colour frame from the same camera reads mean S above 30. That is a clean
two-order-of-magnitude separation with nothing in between, and it is the empirical basis for
`NIGHT_SATURATION_THRESHOLD = 12.0` and for ADR 0019's whole approach — the filter's position is
not exposed by any API on this board, but it is plainly readable off the pixels.

**On auto-exposure the camera is already running at high gain at night** — it reaches luma 132.9,
*brighter* than a locked exposure of 250. It is spending noise to get there. This matters for the
interpretation of the sweeps below.

## Finding 1 — the external IR illuminator delivers a large, consistent gain at every range

### Locked exposure 100 — 83 lit frames, 48 dark frames, 8 cycles

| Band | Luma lit (sd) | Luma dark (sd) | Δ luma | Sharp lit | Sharp dark | Δ sharp |
|---|---|---|---|---|---|---|
| full | 85.31 (3.8) | 60.71 (0.8) | **+24.60 (+40.5%)** | 123.4 | 98.8 | +24.5 |
| far | 74.80 (4.1) | 55.40 (0.8) | +19.41 (+35.0%) | 121.4 | 100.3 | +21.1 |
| **treeline** | 90.60 (4.9) | 64.09 (0.8) | **+26.51 (+41.4%)** | 149.5 | 95.8 | **+53.7** |
| mid | 88.91 (4.6) | 63.40 (0.9) | +25.51 (+40.2%) | 120.7 | 99.0 | +21.7 |
| near | 89.87 (5.3) | 61.29 (0.9) | +28.58 (+46.6%) | 100.8 | 101.3 | −0.5 |

### Locked exposure 156 — 80 lit frames, 48 dark frames, 8 cycles

| Band | Luma lit (sd) | Luma dark (sd) | Δ luma | Sharp lit | Sharp dark | Δ sharp |
|---|---|---|---|---|---|---|
| full | 113.55 (4.9) | 84.42 (0.9) | **+29.13 (+34.5%)** | 143.9 | 90.3 | +53.5 |
| far | 102.09 (3.7) | 77.92 (0.9) | +24.17 (+31.0%) | 143.2 | 91.3 | +51.9 |
| **treeline** | 119.46 (5.2) | 88.15 (1.0) | **+31.31 (+35.5%)** | 186.5 | 95.2 | **+91.2** |
| mid | 117.55 (6.5) | 87.90 (0.9) | +29.65 (+33.7%) | 138.4 | 90.1 | +48.3 |
| near | 118.29 (8.2) | 85.42 (0.8) | +32.87 (+38.5%) | 104.0 | 84.8 | +19.3 |

**No clipping in any run** — the illuminator never blows out the near field, so there is headroom
if a stronger emitter or a longer pulse is ever wanted.

### What this says

The illuminator works, and it works where it needs to. Across both exposures the luma gain is
+31% to +47% on every band, with dark-frame standard deviations under 1.0 — the effect is far
outside the noise, and it repeated across all 16 cycles with no drift.

**The operationally important result is the sharpness gain at the treeline: +53.7 at exposure 100
and +91.2 at exposure 156, roughly a doubling of resolved detail.** That band is the vegetation
edge, the place an elephant first becomes visible as it leaves cover, and it is the hardest part of
the frame — furthest from the emitter, most cluttered, lowest contrast. The illuminator improves it
most. `far` gains almost as much (+51.9 at exposure 156).

`near` is the exception: luma rises the most (+38.5%) but sharpness barely moves (+19.3 at
exposure 156, −0.5 at exposure 100). The foreground is close enough to be adequately exposed
already, so extra light adds brightness without adding recoverable structure. This is the expected
inverse-square behaviour and it is fine — the near field was never the problem.

Higher base exposure amplifies the sharpness benefit (treeline +53.7 → +91.2) while slightly
*reducing* the proportional luma benefit (+41.4% → +35.5%), consistent with the illuminator lifting
the whole scene further above the sensor's noise floor.

### The honest caveat

**Every number above was measured with exposure locked. The deployed pipeline runs the camera on
auto-exposure.** These runs prove the illuminator puts real, substantial, well-distributed photons
onto the sensor at all four range zones. They do **not** directly predict the detection improvement
in the shipped AGC configuration, because AGC will convert some of that extra light into reduced
sensor gain rather than increased brightness — which should be a genuine noise win, but is a
different quantity from the one measured here, and the one auto-exposure run taken was too short
(4 lit frames) to characterise it. Logged in `docs/KNOWN_GAPS.md`; needs an attended run with a
real target in frame.

**No detections in any sweep, lit or dark: 0 Elephant, 0 Boar, max confidence 0.000, in all
131+128 frames.** The backyard was empty, so this is the correct answer and is a useful negative
control — but it means the illuminator's effect on *detection* (as opposed to image quality) is
still unmeasured. The model's positive control was established separately at 9/10.

## Finding 2 — our own LED wings do not blind our own camera

Both wings, gain 100%, 2500 ms bursts, locked exposure 100. Six baseline frames with the LEDs off
immediately before each burst, five frames captured during it. All four night patterns tested.

| Pattern | Luma off | Luma during (mean) | Δ | during min–max | sd | Sharp during | clip_hi | Vision (off / during) |
|---|---|---|---|---|---|---|---|---|
| 2 `fast_strobe` | 58.66 | 57.94 | **−0.72** | 57.38–58.48 | 0.35 | 96.0 | 0.000 | 0 / 0 |
| 4 `sweep` | 58.46 | 58.17 | **−0.28** | 57.70–58.63 | 0.35 | 96.2 | 0.000 | 0 / 0 |
| 5 `pulse_both_sync_11hz` | 58.45 | 58.11 | **−0.34** | 57.20–58.53 | 0.49 | 96.6 | 0.000 | 0 / 0 |
| 6 `flicker_both_independent` | 58.45 | 58.15 | **−0.30** | 57.34–58.46 | 0.41 | 96.6 | 0.000 | 0 / 0 |

All four ACKed `[1, 1, null, true]`.

The deltas are −0.28 to −0.72 luma against a within-burst standard deviation of 0.35–0.49. That is
at or barely above the frame-to-frame noise of the sensor. Sharpness sits flat at 96.0–96.6 across
every pattern, against a 96-ish baseline. **`clip_hi` is exactly 0.000 for every pattern** — not a
single pixel is blown out, including by the 11 Hz sync pattern, the most aggressive one we have.

**Conclusion: detection and deterrence can overlap.** There is no need to serialise deter → wait →
re-detect. The reflex loop can keep the camera running through an LED burst and capture evidence of
the animal's actual reaction *while* the wings are firing — which is exactly what the encounter-aware
cadence work in the Item C proposal needs, and it is what makes "did the deterrent work?" an
answerable question in real time rather than a guess.

### Frame-by-frame visual check — added 2 September

The photometric null was followed up by pulling the saved JPEGs and inspecting them directly, since
a flat luma number could equally mean "LED does not reach the sensor" or "LED reaches the sensor
but AGC/JPEG hid it". The frames settle it. A max-gain both-wings frame (pattern 5, 11 Hz sync,
30 ms and 1.23 s into the burst), a `flicker_both_independent` frame, and the LED-off / IR-off
reference are **visually indistinguishable**: same treeline foliage, same soft glow at bottom-right
(that glow is the camera's *onboard* IR reflecting off the nearest foliage and the enclosure lip,
present in every night frame), and in the LED frames **no hotspot, no bloom, no lens flare, no
edge flare, no pool of light anywhere.** Nothing in the image indicates a white emitter fired.

**This was shot with the camera, the external IR emitter and both LED wings mounted in the
production 3D-printed enclosure, in the orientation the unit is deployed in the field.** So it is
not a bench approximation of the geometry — it is the geometry. In that geometry the LED wings
contribute exactly zero photons to the camera frame.

Three consequences follow:

1. **The optical-interference question is closed.** Detection and deterrence overlap with no
   measurable cost to the image. The reflex loop can hold the camera open through an LED burst.
2. **The camera gets no illumination help from the LED wings** — only the IR path (external pulse
   plus the camera's onboard emitters) lights the scene for the detector. This is intended (white
   light at night would wreck the monochrome exposure and confuse the IR-cut filter) but it means
   the LED contributes nothing to night image quality and should never be counted on to.
3. **There is no optical confirmation that the LED fired.** The camera cannot see the wings, so
   "did the LED actually fire during that encounter?" cannot be answered from vision — it would
   have to come from MCU-side current sensing. Noted for any future fire-verification work.

**What this check still does not establish:** whether the LED *beam* lands where an approaching
elephant's head and eyes will be. The camera cannot see the beam at all, so this is not a
camera-answerable question — it needs a person standing in the approach zone at night looking back
at the unit, or a witness target placed there. Logged in `docs/KNOWN_GAPS.md` as a physical field
check, no longer as a camera/FOV ambiguity.

### Enclosure geometry — from an assembly photo, 2 September

The assembled unit resolves the "aimed correctly vs misaimed" ambiguity above in favour of reading
1 (design working). The two white-LED wings are ~5 star emitters each, wired in parallel, seated in
deep recessed vertical channels on the left and right faces. Full-height walls separate each channel
from the central bay that holds the camera and the IR array. Those walls shroud the wings: the
emitters face forward, parallel to and boresighted with the camera axis — they project into the
same volume the camera watches — but their lateral spill is physically blocked from the lens. That
is the mechanism behind the zero-photon result, and it means the wings are not misaimed relative to
an approaching animal; the only open LED-beam question is throw and intensity at range, which is a
field check.

Also visible: the camera carries its own onboard IR emitters flanking the lens (confirming the
"dark" baseline frames in Finding 1 are onboard-IR-lit, with the external array as the boost); the
external IR is a wide-flood array of roughly 40 through-hole emitters, not a single high-power
source. A horizontal shelf baffles the camera recess from the IR array recess.

**Enclosure material.** The bench rig is printed in PETG-HS. The field units will be ABS or ASA,
both of which have a higher heat-deflection temperature than PETG-HS, so the enclosure gives the
LED wings and the IR array *more* thermal margin in the field than the rig they were characterised
on, not less — the thermal findings here are a conservative bound.

**IR board onboard photocell — resolved, not an open item.** Only the illuminator's power pins are
used, switched by the pin-7 MOSFET; the board's onboard CdS cell is not in the control path and is
not relied on for anything. There is one night gate, `perception/night.py` (ADR 0019); the earlier
"two independent night gates that can disagree" concern does not apply.

One item follows for the field-readiness checklist, logged in `docs/KNOWN_GAPS.md`:

- **Wing continuity check.** The wings are wired in parallel, so a single open-circuit emitter
  drops only that emitter and dims the wing slightly rather than dark-failing the whole string
  (the series-wiring failure mode does not apply). Still worth a visual/continuity check at
  pre-deployment and a note in the maintenance procedure, since a shorted emitter or a broken
  common lead would still take a wing down.

Note also that the LED sweep at gain 100% consumed roughly 40 s of the ~2 min nightly LED-on
budget; the remainder was reserved.

## Finding 3 — the external IR illuminator is a pulsed vision flash by design; continuous-on is not an available mode

This section answers a direct question: *should the external IR run continuously, or in interval
bursts, and which gives the clearest image at maximum range?* Part of the answer is architectural,
part is in the data above, and part is a measurement a supervised session still has to make.

### Continuous-on is not a knob — the firmware caps IR at a 10% duty cycle

`device/mcu/src/config.h`: `IR_PULSE_MAX_MS = 500`, `IR_MIN_INTERVAL_MS = 5000`. The MCU clamps
every IR request to at most a 500 ms pulse no more than once per 5 s, and the MPU already requests
the maximum on every pulse (`IR_WATCH_PULSE_MS = 500`, paced by `IR_WATCH_MIN_INTERVAL_S = 5.0` so
the request matches the cap rather than being clamped down to it), so **in the field the
illuminator is always a full 500 ms pulse and never longer.** Running it
continuously would require a firmware change plus a thermal solution for the emitter and its
MOSFET plus a power-budget revision against ADR 0012's 10-day autonomy — a continuous near-IR
emitter is a large always-on load, and this part is specified as a capture flash, not area
lighting. It is not a tuning parameter that can be turned up.

`config.h` line 433 comments the emitter as **940 nm**; the rig notes for this soak recorded the
external emitter as **850 nm** (the camera's *onboard* emitters are 940 nm). This wants confirming
against the actual part — it matters for range (see below) — and is logged as a doc/hardware
discrepancy to resolve, not settled here.

### Does pulsing cost image quality versus continuous? For this detector, no

The camera integrates light only over its exposure window, which on this sensor runs from a few ms
up to roughly 200 ms depending on AGC state. A 500 ms pulse brackets that window completely with
margin. The vision runner does inference on demand at ~5 FPS during an event, not on every sensor
frame, so **one pulse per inference is sufficient** — continuous illumination would only help if
every frame at video rate had to be lit (frame-to-frame tracking), which this pipeline does not do.
Finding 1's +31–47% luma and treeline sharpness near-doubling were all obtained from single 500 ms
pulses, so the pulsed mode is already delivering the measured benefit.

### The real open question: does the pulse reliably land inside the captured frame in the field?

Finding 1 was measured with a harness that guaranteed pulse/capture overlap by classifying frames
*after* capture. The deployed path is different: `reflex_loop.py` fires `pulse_ir()` on its own
thread concurrently with `capture_burst()`, because the MCU's `pulse_ir()` blocks for the full
pulse. Whether the grabbed evidence frame consistently falls within that 500 ms window in the
field — across USB-UVC driver latency, `docker exec` cold-start jitter (measured at 1–3 s in
[Method](#method)), and the camera's own frame cadence — is **not yet verified end to end.** If
frames sometimes miss the pulse, the image for that event reverts to the onboard-IR-only "dark"
baseline (still usable — the dark frames in Finding 1 are onboard-IR-only — but without the gain).
The fixes, in order of preference, would be an explicit capture/pulse handshake, then a longer
pulse (Finding 1 shows zero clipping, so there is optical and — within limits — thermal headroom),
**not** continuous-on.

### What actually limits clear maximum range

| Limiter | What the data / hardware says | Lever |
|---|---|---|
| Inverse-square falloff | `far`/`treeline` gain +19–24 luma vs `near` +29–33 — the emitter is already weakest exactly where range matters | emitter power, beam angle |
| Exposure / sensor gain | exp 156 gave ~2× the treeline sharpness gain of exp 100 (+91.2 vs +53.7) — more integration time reaches further | raise base night exposure — but see motion blur |
| Motion blur | unmeasured; the Finding 1 scene was static, a moving elephant at the treeline is not — this is the blocker on the exposure-raise | bench protocol, Item C |
| Wavelength | 850 nm has roughly double the silicon response of 940 nm (faint visible red glow); 940 nm is fully invisible but dimmer — range favours 850 | confirm which the external part is (above) |
| Emitter type | the external source is a wide-flood array of ~40 through-hole LEDs (assembly photo), not a single high-power emitter — good coverage width across the approach fan, moderate range | supplementary narrow-beam emitter if range is short |
| Beam optic | narrow throws further / covers less width; wide covers the approach fan / dies sooner — unmeasured | emitter optic choice |
| Atmospheric | fog and heavy rain scatter near-IR badly | none — accept reduced range in those conditions |

**Best setting supported by current evidence:** the 500 ms pulse (already the firmware maximum),
base exposure raised toward 156 *pending the motion-blur check*, and treeline (the vegetation edge)
accepted as the practical detection horizon — which is exactly the band Finding 1 shows the pulse
improves most, so the design is already aimed correctly. No change is warranted from desk analysis
alone; the exposure raise needs the moving-target measurement.

### What a supervised session should measure

Auto-exposure (the deployed config), with a person or animal-sized target at marked standoffs
(≈5 / 10 / 15 / 20 m): detection rate versus range with the pulse and without it; whether the
evidence frame lands inside the pulse window across repeated real firings; exp 100 vs 156 vs auto
with the target *moving*. This is the run that converts Finding 1's image-quality numbers into a
range-versus-detection curve for the shipped configuration.

## Finding 4 — best night camera configuration: locked exposure ≈ 256 with the 500 ms IR pulse

An overnight battery (`/home/arduino/vdiff/night_battery.sh` + `night_battery2.sh`, board-time
19:42–20:45 on 1 Sept ≈ 00:20–01:25 IST 2 Sept) swept camera exposure with and without the IR
pulse to find the configuration that gives the clearest night image with the fewest false
positives. All runs were within firmware limits (IR 500 ms / ≥5 s, no LED beyond a small budget);
`boot_id` held and container `RestartCount` stayed 0 throughout; board sensor temperature stayed
39–44 °C across the whole ~1 h run with no climb.
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

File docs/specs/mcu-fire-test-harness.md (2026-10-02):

# Spec — MCU manual fire-test harness

Status: ready to build. Written by the planning session, 14 Aug, against the actual current state of
`device/mcu/src/` (not generic advice — every convention below is copied from code already in the repo).
Build exactly this; if something here conflicts with a file you're looking at, the real file wins and
the conflict should be logged in `docs/KNOWN_GAPS.md`, not silently resolved either way.

## Why this exists

`horn.cpp`, `led.cpp`, `ir.cpp` are real, complete drivers — nobody has fired any of them on real
hardware yet. Before any decision logic (fusion, bandit, Bridge wiring) gets layered on top, someone
needs to confirm the horn, LEDs, and IR illuminator physically switch on command. This harness is a
serial-command bench tool for exactly that: type a character in App Lab's Serial Monitor, one actuator
fires once, the full ack prints back. Nothing autonomous, nothing Bridge-registered — a human has to
type the command each time, which is the point: it cannot fire anything unattended.

## Scope boundary — read this before writing any code

This harness calls `drive_horn()`, `drive_led()`, `pulse_ir()` **directly as C++ functions**. It does
**not** touch `Bridge.provide()`. `docs/KNOWN_GAPS.md` and `device/mpu/bridge/rpc.py`'s module
docstring both document that Bridge registration for these three functions is deliberately deferred to
its own hardware session, one function at a time, because a past registration attempt broke every
previously-working Bridge function on the same sketch. Do not register anything with Bridge as part of
this feature. If that temptation comes up, stop and flag it instead.

## Files to add

Both files are new, flat in `device/mcu/src/` — per ADR 0010, `src/` has no subfolders and every file
sits at the same depth with plain `#include "whatever.h"`. Don't create a subfolder for this.

- `device/mcu/src/fire_test.h`
- `device/mcu/src/fire_test.cpp`
- `device/mcu/tests/test_fire_test/test_fire_test.cpp` (new test directory, mirrors `test_rule_gate/`)

## `fire_test.h` — public surface

```cpp
#ifndef FIRE_TEST_H
#define FIRE_TEST_H

#include <stdint.h>

// One serial-command byte maps to exactly one bench actuator target, or to
// no target at all. Pure function, no hardware calls, no side effects -
// this is the one piece of the harness that's host-testable without a
// board, same discipline as rule_gate.h's pure core (ENGINEERING_CONVENTIONS.md 4).
enum class fire_test_target { kNone, kHorn, kLedWingLeft, kLedWingRight, kIr, kHelp };  // renamed 30 Aug, was kLedWhite/kLedBlue

fire_test_target fire_test_parse_command(char c);

void fire_test_init();
void fire_test_service(uint32_t now_ms);

#endif  // FIRE_TEST_H
```

## `fire_test.cpp` — behavior

Command map (single ASCII digit per actuator, kept deliberately unambiguous — no letter overlaps with
anything else the firmware prints or expects):

| Key | Target | Default request |
|---|---|---|
| `1` | Horn | `duration_ms=FIRE_TEST_HORN_DURATION_MS, gain_pct=FIRE_TEST_HORN_GAIN_PCT, track_id=FIRE_TEST_HORN_TRACK_ID` |
| `2` | LED white | `duration_ms=FIRE_TEST_LED_DURATION_MS, gain_pct=FIRE_TEST_LED_GAIN_PCT` |
| `3` | LED blue | same constants as white, different channel |
| `4` | IR | `duration_ms=FIRE_TEST_IR_DURATION_MS, gain_pct=FIRE_TEST_IR_GAIN_PCT` |
| `?` | — | prints the command menu, fires nothing |

`fire_test_parse_command()` is a plain `switch` on the char, no I/O, returns the enum — this is the
function `test_fire_test.cpp` exercises directly.

`fire_test_service(uint32_t now_ms)`:
1. `if (!Serial.available()) return;` — non-blocking poll, same shape as `geophone_service()`'s
   per-loop-iteration style in `main.cpp`.
2. Read one byte, call `fire_test_parse_command()`.
3. On `kHorn`/`kLedWingLeft`/`kLedWingRight`/`kIr`: build the request struct from the table above, call the
   real driver function (`drive_horn`, `drive_led`, `pulse_ir` — exact signatures already in
   `horn.h`/`led.h`/`ir.h`, don't redeclare them), then print the **full ack**, not just true/false:

   ```cpp
   Serial.print("[firetest] horn allowed=");
   Serial.print(ack.allowed);
   Serial.print(" duration_ms=");
   Serial.print(ack.duration_ms);
   Serial.print(" gain_pct=");
   Serial.print(ack.gain_pct);
   Serial.print(" clamped=");
   Serial.println(ack.clamped);
   ```

   This follows the `[tag] key=value key=value` convention used by `log_trigger()` in
   `state_machine.cpp`, and directly addresses the KNOWN_GAPS note that `ack: bool` alone is too lossy
   to be useful — the harness's whole job is to make clamped/allowed/actual-values visible.
4. On `kHelp` or unrecognized byte: print the four-line command menu.

**Cooldown is expected to refuse repeated commands — this is not a bug.** `rule_gate_apply()` already
enforces `HORN_COOLDOWN_MS=30000`, `LED_COOLDOWN_MS=20000`, `IR_MIN_INTERVAL_MS=5000` per actuator.
Pressing `1` twice inside 30s will print `allowed=false` the second time. Say so explicitly in the
printed menu (`? ` output) so whoever's running the test doesn't think it's broken.

**This call blocks.** `horn.cpp`'s fire sequence is a blocking `delay()` chain (up to
`HORN_BURST_MAX_MS=3000` plus the amp-enable delay); `led.cpp`/`ir.cpp` block for their own
`duration_ms`. During a manual fire-test command, `geophone_service()` and `lora_service()` in the same
`loop()` iteration are blocked too, for up to ~3.8 s in the horn case. Acceptable for a bench-only,
human-triggered tool — call this out as a one-line comment in `fire_test.cpp`, don't silently leave it
implicit the way a reviewer would have to go find out for themselves.

## Bench-safe default values — add to `config.h`'s bench-flags block

Same section as `SEISMIC_DEBUG_STREAM_RAW` and friends, same banner discipline (must default to a form
that's safe to ship, rationale comment, "confirm before `sync-to-board.sh`"):

```c
// Manual fire-test harness - serial-command-triggered single fire of
// horn/LED/IR for hardware bring-up verification. Human types a digit into
// App Lab's Serial Monitor; nothing fires without that keystroke, so this
// has no autonomous trigger path. Still gated to 0 by default: the point of
// field builds is that bench-only surface area doesn't exist in them.
#define FIRE_TEST_HARNESS 0

// Bench defaults - short and conservative, real safety backstop is still
// rule_gate_apply()'s per-actuator caps (HORN_GAIN_MAX_PCT etc.), these are
// just sane starting points for a desk-bench test, not a duplicate limit.
#define FIRE_TEST_HORN_DURATION_MS 500   // well under HORN_BURST_MAX_MS=3000
#define FIRE_TEST_HORN_GAIN_PCT 30.0f    // under HORN_GAIN_MAX_PCT=60, desk-volume not field-volume
#define FIRE_TEST_HORN_TRACK_ID 1        // AT+PLAYNUM index 1 (bee, ADR 0016 C) - bench wiring check, content arbitrary
#define FIRE_TEST_LED_DURATION_MS 1000
#define FIRE_TEST_LED_GAIN_PCT 50.0f
#define FIRE_TEST_IR_DURATION_MS 200     // under IR_PULSE_MAX_MS=500
#define FIRE_TEST_IR_GAIN_PCT 100.0f     // IR is invisible, thermal is the only real constraint
```

## Wiring into `main.cpp`

Same `#if`/`#endif` shape already used for `SEISMIC_DEBUG_STREAM_RAW`'s `Bridge.begin()`/`Bridge.update()`
carve-out — don't invent a different gating style:

```cpp
void setup() {
  Serial.begin(CONSOLE_BAUD);
#if SEISMIC_DEBUG_STREAM_RAW
  Bridge.begin();
#endif
#if FIRE_TEST_HARNESS
  fire_test_init();
#endif
  geophone_init();
  horn_init();
  led_init();
  ir_init();
  lora_init();
  state_machine_init();
}

void loop() {
  const uint32_t now_ms = millis();
#if SEISMIC_DEBUG_STREAM_RAW
  Bridge.update();
#endif
#if FIRE_TEST_HARNESS
  fire_test_service(now_ms);
#endif
  geophone_service();
  lora_service(now_ms);
  state_machine_tick(now_ms);
}
```

`fire_test_init()` can be a no-op or just print the command menu once at boot — your call, keep it
small either way.

## Tests — `test_fire_test/test_fire_test.cpp`

Only `fire_test_parse_command()` is host-testable (it's pure — no `Serial`, no hardware, matches the
"pure core" testing discipline `test_rule_gate.cpp` already follows). The actual fire behavior can only
be verified live on the board via App Lab's browser Serial Monitor — **not** `arduino-cli monitor`,
which ADR 0010's addendum confirms delivers zero bytes even for an unconditional periodic print. Don't
try to test the live fire path from a host build; it's a hardware-session task, not a `pio test` task.

Match `test_rule_gate.cpp`'s exact shape: `#include <unity.h>` first, empty `setUp()`/`tearDown()`,
`static void test_<behavior>(void)` names, `_MESSAGE` assertion variants, every test explicitly listed
in `main()`. Minimum coverage:

- `test_digit_1_maps_to_horn`
- `test_digit_2_maps_to_led_wing_left`
- `test_digit_3_maps_to_led_wing_right`
- `test_digit_4_maps_to_ir`
- `test_question_mark_maps_to_help`
- `test_unrecognized_byte_maps_to_none`
- `test_whitespace_and_newline_bytes_map_to_none` (Serial Monitor sends a line terminator — make sure
  `\n`/`\r` don't get mis-parsed as a command)

Run with `pio test -e native` from `device/mcu/`, same as the existing suite.

## Docs to update as part of this change

- `docs/KNOWN_GAPS.md`: add a line noting the fire-test harness now exists as the intended mechanism to
  bench-measure `HORN_AMP_ENABLE_DELAY_MS` (currently invented, per the existing gap entry) and to
  sanity-check the provisional burst/cooldown constants — don't mark those gaps closed, just note the
  tool now exists to close them.
- Commit message, Conventional Commits, e.g. `feat(mcu): add serial fire-test harness for horn/led/ir bench verification`.
- No AI/assistant attribution anywhere — commit message, code comments, this spec's own presence
  nowhere referenced in-repo. Standard repo-wide rule, not new to this feature.

## DFPlayer PRO (DFR0768) provisioning + bring-up checklist

The horn fire path (ADR 0015 / 0016) assumes the module has been loaded with the five deterrence
tracks in a specific order and answers on the D9/D10 software UART. Do this once per module, before
the harness's `1` command means anything, and re-verify it whenever the flash contents change.

### Load the audio (once per module)

1. Trim/normalise the five ADR 0016 Decision C tracks to short clips (predator growls ~6–7 s, bee
   swarm trimmed from 2:40 to a representative clip; all well under `HORN_BURST_MAX_MS=3000`). Do
   not load the raw Freesound downloads.
2. Connect the DFR0768's USB-C port to a host — it enumerates as a mass-storage volume (128 MB
   onboard flash, no SD card). If files are already present, delete them all first so directory
   order starts clean.
3. Copy the tracks **one at a time, in the order below**, waiting for each copy to finish before
   starting the next — `AT+PLAYNUM=<n>` indexes by FAT directory (copy) order, not by any number in
   the filename. This order matches `device/mpu/cognition/config.py`'s `HORN_CONTENT_LIBRARY`:
   - index 1: bee swarm — "Intense Angry Bee Swarm" (Freesound 788025, CC0)
   - index 2: tiger roar — "tiger roar" (Freesound 149190, CC-BY 4.0)
   - index 3: lion roar — "Lion Roar" (Freesound 212764, CC-BY 3.0)
   - index 4: air horn — "airhorn.wav" (Freesound 64476, CC0)
   - index 5: firecracker — "Firecracker_01.wav" (Freesound 101130, CC-BY 4.0)
4. Eject cleanly. Carry the CC-BY attributions for tracks 2, 3, 5 into the project's public
   materials (ADR 0016 Decision C).

### Verify on the board (bring-up session, module wired, harness flashed)

1. Confirm the software UART works at all: the single highest-priority bring-up check (ADR 0015
   Decision A). If D9/D10 `SoftwareSerial` does not work on this Zephyr core, nothing below matters
   and the KEY-pin fallback (`AUDIO_TRIGGER_PIN`) is the contingency.
2. First `1` after power-on: `horn.cpp` sends `AT+PLAYMODE=3` then `AT+PROMPT=OFF` before the first
   `AT+PLAYNUM`. Confirm the burst plays once and stops itself (does not loop) and that no
   confirmation beep plays ahead of the clip. Play mode is re-sent every boot because the DFR0768
   does not reliably persist it.
3. Walk `FIRE_TEST_HORN_TRACK_ID` through 1..5 (edit, reflash, or drive it from a temporary harness
   command) and confirm each index plays the track listed in the load table above. A wrong track for
   an index means the copy order was not clean — reload.
4. Confirm `AT+PLAYNUM` on this firmware auto-starts playback rather than only cueing it (ADR 0015
   open item). If it only cues, `horn.cpp`'s fire sequence needs a follow-up `AT+PLAY` — flag, don't
   patch silently.
5. Confirm the `DACL`/`DACR` line-out into the TPA3116D2 is live regardless of `AT+AMP` state — the
   design bypasses the module's onboard amp and never sends `AT+AMP`.
6. Use the harness's `1`-twice-within-30 s check to measure `HORN_AMP_ENABLE_DELAY_MS` against real
   DFPlayer seek latency (existing `KNOWN_GAPS.md` item).

## Verification checklist before calling this done

1. `pio test -e native` passes, all seven `test_fire_test` cases plus the existing suite green.
2. `pio run -e native` (or whatever the field-target env is) compiles with `FIRE_TEST_HARNESS 0` —
   confirms the flag truly compiles out, not just logically disabled.
3. Flip to `FIRE_TEST_HARNESS 1` locally, confirm it also compiles.
4. Flash via App Lab (per ADR 0010, the only real flash path), open App Lab's browser Serial Monitor,
   type `1`, confirm the horn fires and the `[firetest]` ack line prints. Repeat for `2`, `3`, `4`.
   Press `1` twice within 30s, confirm the second attempt prints `allowed=false` — that's the cooldown
   gate working, not a failure.
5. Set `FIRE_TEST_HARNESS` back to `0` before this ever goes near `scripts/sync-to-board.sh` for a
   node headed to the field.

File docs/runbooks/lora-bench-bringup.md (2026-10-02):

# Runbook: LoRa bench bring-up (UNO Q + Grove LoRa-E5 + SenseCAP M2 + ChirpStack)

**Purpose.** A step-by-step path from a factory-fresh Arduino UNO Q, a Grove LoRa-E5 and a boxed
SenseCAP M2 gateway to a real LoRaWAN OTAA join and uplink on India's IN865 band, landing in a
local ChirpStack. Written 2026-10-01 while doing it for the first time on a second, bench-only
UNO Q (2 GB). Each step says what was actually observed.

**Status of each part (2026-10-01):**

| Part | State |
|---|---|
| UNO Q factory setup, update, app flashed | Done |
| Gateway on IN865, Packet Forwarder to the laptop | Done (settings saved) |
| ChirpStack running on the laptop | Done (`docker compose up -d`) |
| Gateway registered and online in ChirpStack | Done (stats arriving on `in865`) |
| Device profile + device registered | Profile and application done; device pending |
| E5 wired, OTAA join, first uplink | Wired; JoinRequests reach ChirpStack (device not yet registered) |

Related: `docs/research/sensecap_gateway_in865_chirpstack_setup.md` (August research pass),
ADR 0029 (USART1 shared between DFPlayer and LoRa-E5), `hardware/PIN_MAP.md`,
`docs/runbooks/mcu-flash-uno-q.md`.

---

## Part 1 — Factory UNO Q: first access, network, SSH

A factory UNO Q ships with SSH disabled, no SSH host keys and the `arduino` user's password
expired. The only way in is ADB over the USB-C cable.

1. **ADB.** Use the Android SDK platform-tools `adb` (on this laptop:
   `C:\Users\<user>\AppData\Local\Android\Sdk\platform-tools\adb.exe`; it is not on `PATH`).
   `adb devices` should list the board by serial.
2. **Set a password first**, before any long job: `adb shell`, then `passwd`. If ADB is the only
   way in and USB drops mid-job, the board is unreachable until a power cycle.
3. **Wi-Fi.** `nmcli` from an ADB shell. From Windows, two traps:
   - PowerShell 5.1 strips embedded double quotes from native-exe arguments, so SSIDs with
     spaces break. Push a small script and run it instead.
   - Piping stdin through `adb shell` does not work from Windows. Put the PSK in a temp file,
     push it, use it, delete it.
   - Git Bash rewrites `/tmp/...` into a Windows path on `adb push`; set `MSYS_NO_PATHCONV=1`.
   - A stale NetworkManager profile gives "key-mgmt property is missing". Delete old wireless
     profiles and create a fresh one with `wifi-sec.key-mgmt wpa-psk`.
   - Only 2.4 GHz networks were visible to the board.
4. **SSH.** `sshd` fails until host keys exist:
   `sudo dpkg-reconfigure openssh-server`, then enable and start `ssh`. Install your public key
   in `~/.ssh/authorized_keys` and verify the host fingerprint on first connect.
5. **Hostname.** `sudo hostnamectl set-hostname <name>` so the bench board is never confused
   with a deployed one.

From here on, use `ssh arduino@<board-ip>` rather than ADB.

## Part 2 — Update the Arduino stack
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

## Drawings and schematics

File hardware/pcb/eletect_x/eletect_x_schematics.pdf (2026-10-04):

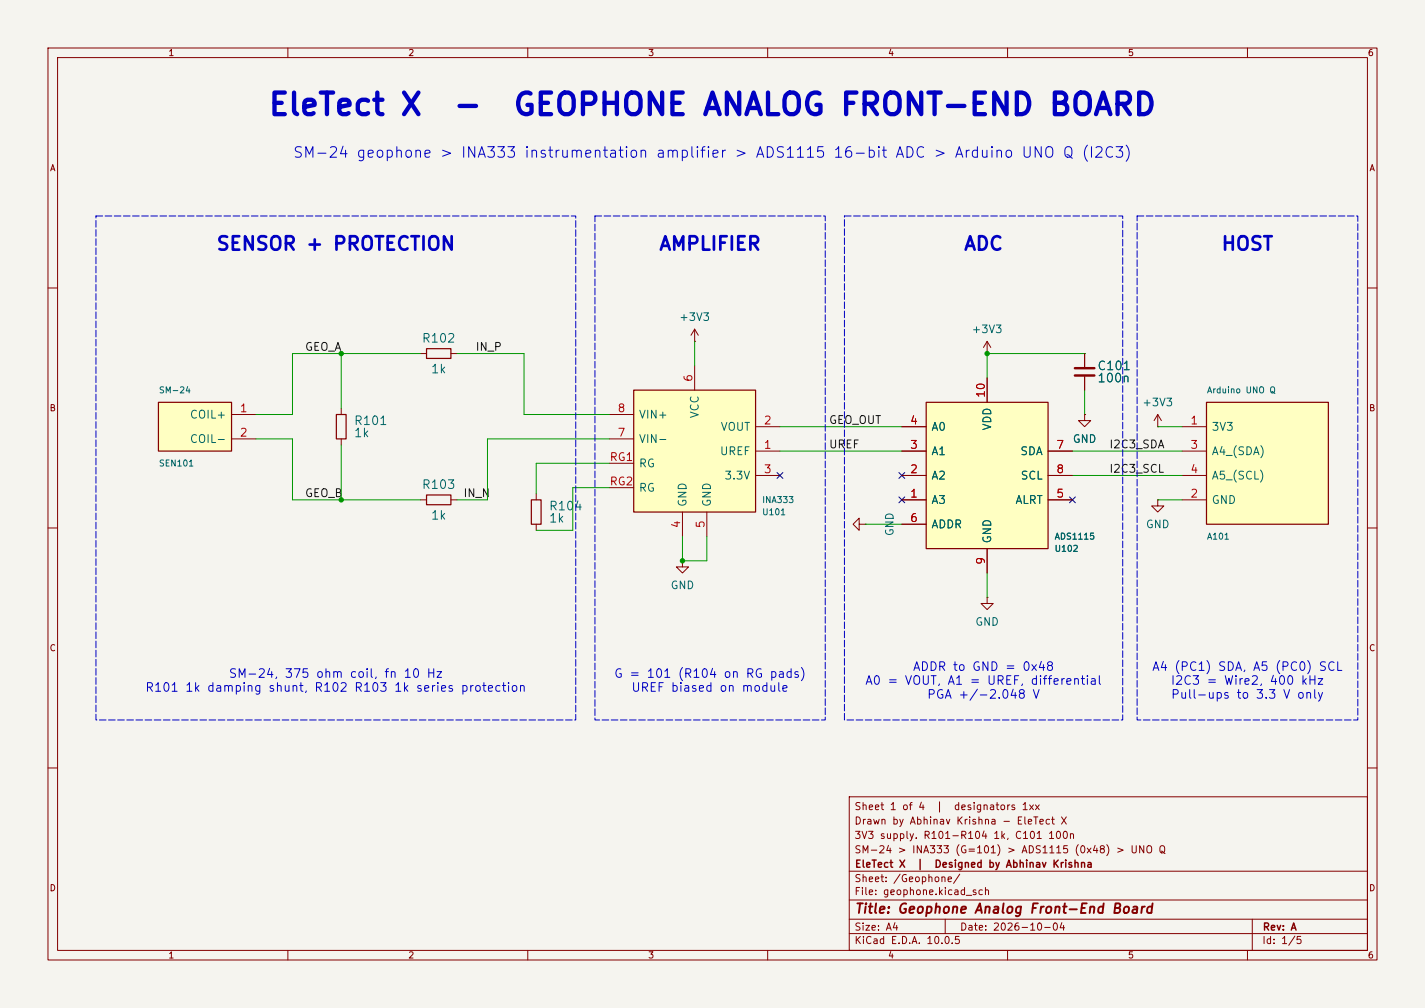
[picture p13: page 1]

EleTect X - GEOPHONE ANALOG FRONT-END BOARD

SM-24 geophone > INA333 instrumentation amplifier > ADS1115 16-bit ADC > Arduino UNO Q (I2C3)

SM-24, 375 ohm coil, fn 10 Hz

G = 101 (R104 on RG pads)
UREF biased on module

A4 (PC1) SDA, A5 (PC0) SCL
I2C3 = Wire2, 400 kHz
Pull-ups to 3.3 V only

R101 1k damping shunt, R102 R103 1k series protection

Sheet 1 of 4 | designators 1xx
Drawn by Abhinav Krishna - EleTect X
3V3 supply. R101-R104 1k, C101 100n
SM-24 > INA333 (G=101) > ADS1115 (0x48) > UNO Q
EleTect X | Designed by Abhinav Krishna
Sheet: /Geophone/
File: geophone.kicad_sch
Title: Geophone Analog Front-End Board

Size: A4 | Rev: A
KiCad E.D.A. 10.0.5 | Id: 1/5

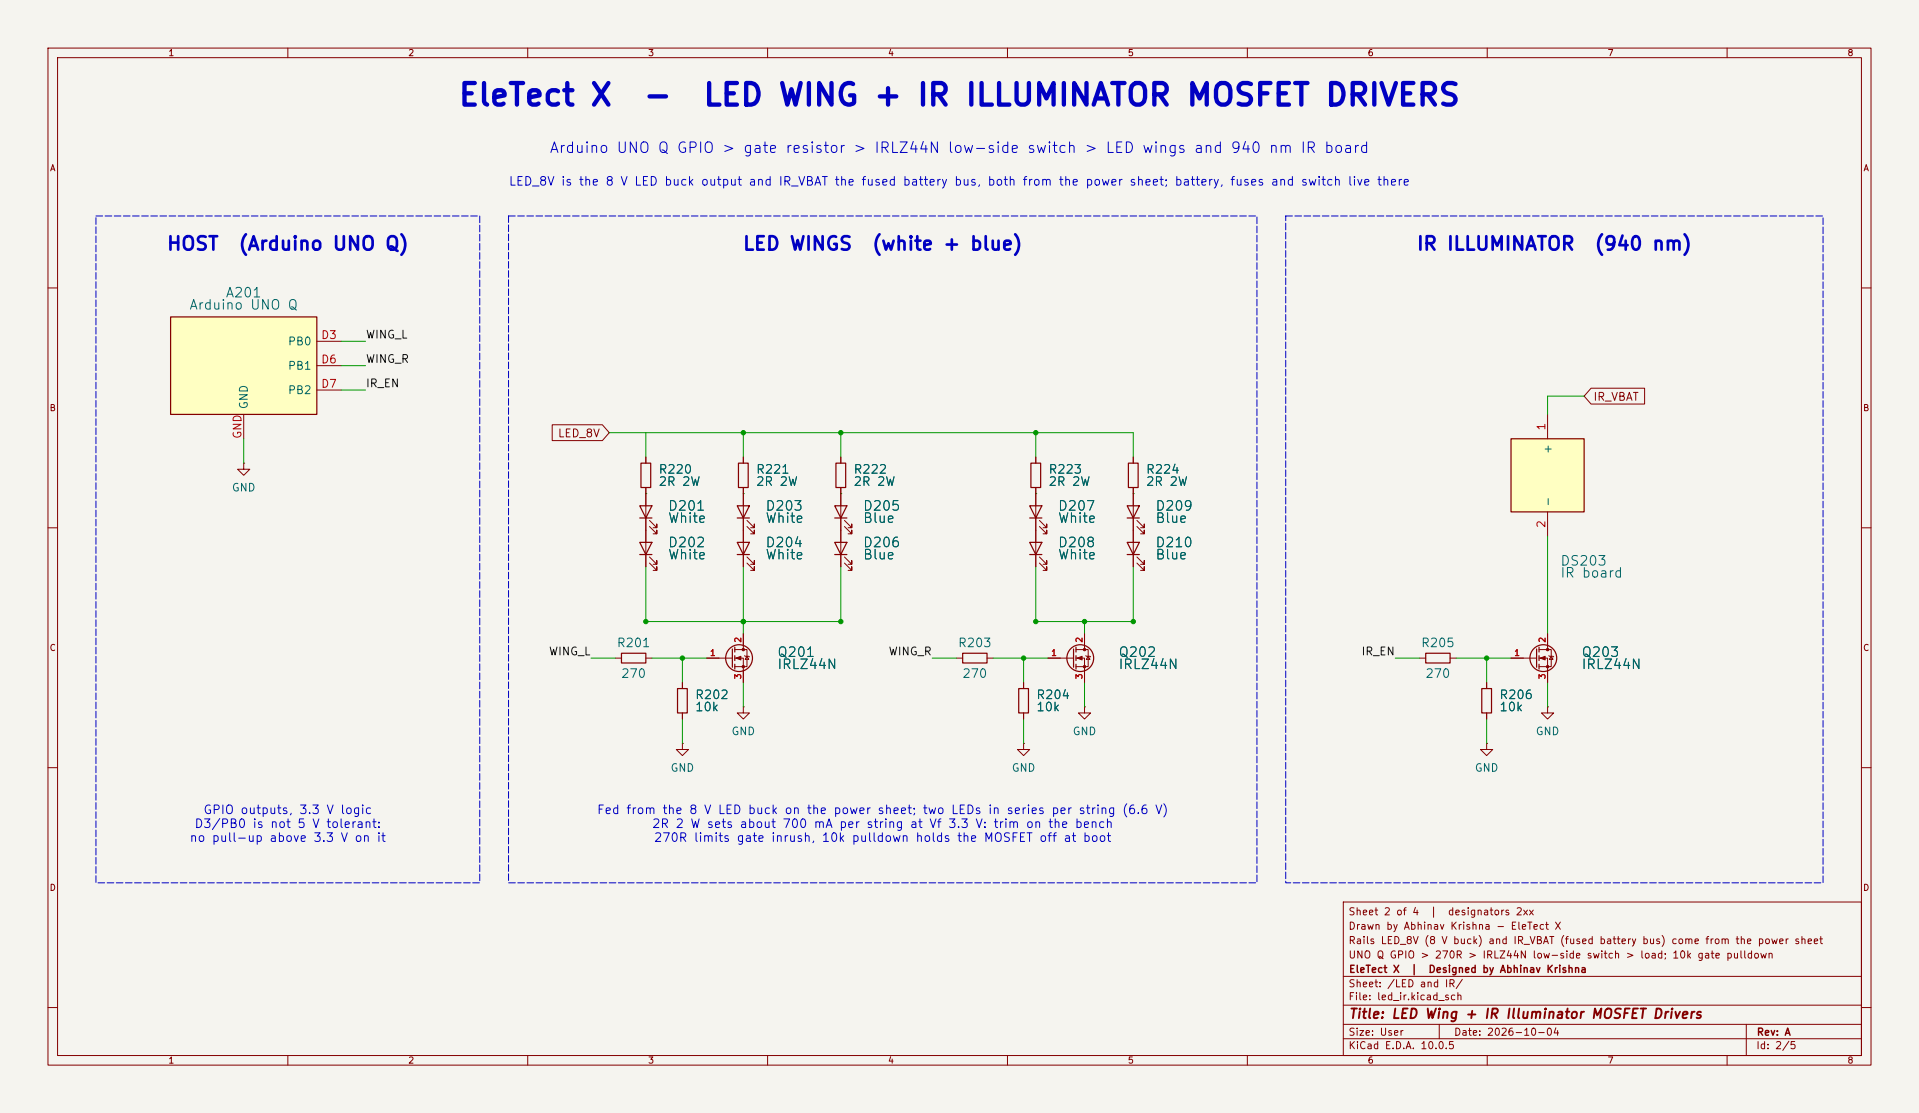
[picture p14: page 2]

EleTect X - LED WING + IR ILLUMINATOR MOSFET DRIVERS

Arduino UNO Q GPIO > gate resistor > IRLZ44N low-side switch > LED wings and 940 nm IR board

LED_8V is the 8 V LED buck output and IR_VBAT the fused battery bus, both from the power sheet; battery, fuses and switch live there

LED WINGS (white + blue)

GPIO outputs, 3.3 V logic
D3/PB0 is not 5 V tolerant: no pull-up above 3.3 V on it

Fed from the 8 V LED buck on the power sheet; two LEDs in series per string (6.6 V)

2R 2 W sets about 700 mA per string at Vf 3.3 V: trim on the bench
270R limits gate inrush, 10k pulldown holds the MOSFET off at boot

Sheet 2 of 4 | designators 2xx
Drawn by Abhinav Krishna - EleTect X
Rails LED_8V (8 V buck) and IR_VBAT (fused battery bus) come from the power sheet
UNO Q GPIO > 270R > IRLZ44N low-side switch > load; 10k gate pulldown
EleTect X | Designed by Abhinav Krishna
Sheet: /LED and IR/
File: led_ir.kicad_sch
Title: LED Wing + IR Illuminator MOSFET Drivers

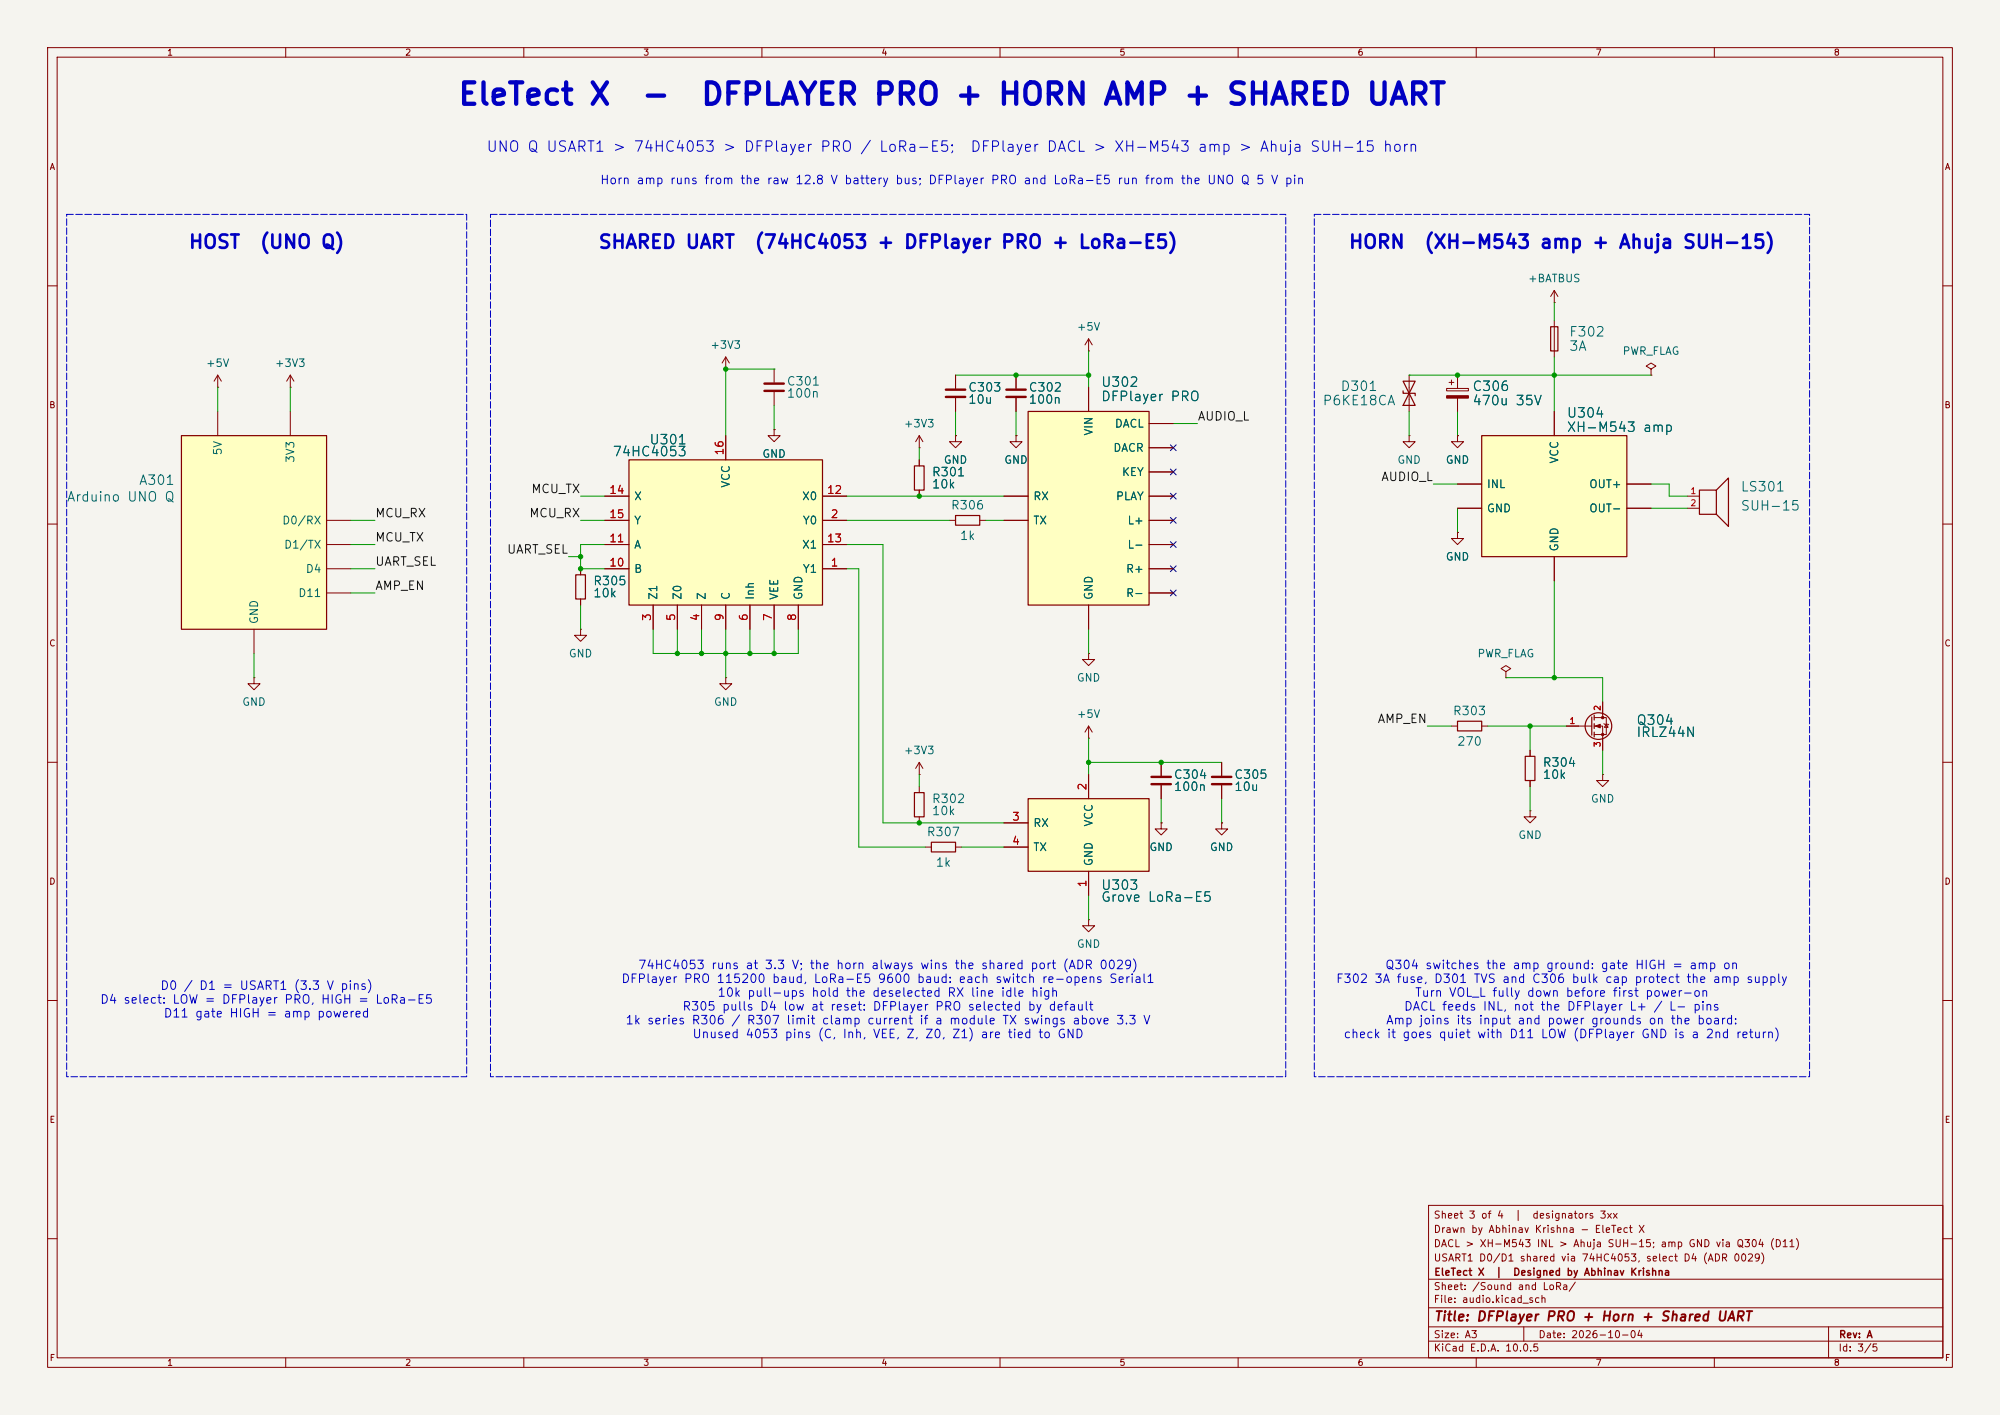
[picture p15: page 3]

EleTect X - DFPLAYER PRO + HORN AMP + SHARED UART

UNO Q USART1 > 74HC4053 > DFPlayer PRO / LoRa-E5; DFPlayer DACL > XH-M543 amp > Ahuja SUH-15 horn

Horn amp runs from the raw 12.8 V battery bus; DFPlayer PRO and LoRa-E5 run from the UNO Q 5 V pin

SHARED UART (74HC4053 + DFPlayer PRO + LoRa-E5)

74HC4053 runs at 3.3 V; the horn always wins the shared port (ADR 0029)
DFPlayer PRO 115200 baud, LoRa-E5 9600 baud: each switch re-opens Serial1

Q304 switches the amp ground: gate HIGH = amp on

F302 3A fuse, D301 TVS and C306 bulk cap protect the amp supply

10k pull-ups hold the deselected RX line idle high
R305 pulls D4 low at reset: DFPlayer PRO selected by default

Turn VOL_L fully down before first power-on
DACL feeds INL, not the DFPlayer L+ / L- pins
Amp joins its input and power grounds on the board:

D4 select: LOW = DFPlayer PRO, HIGH = LoRa-E5

D11 gate HIGH = amp powered

1k series R306 / R307 limit clamp current if a module TX swings above 3.3 V

Unused 4053 pins (C, Inh, VEE, Z, Z0, Z1) are tied to GND

check it goes quiet with D11 LOW (DFPlayer GND is a 2nd return)

Sheet 3 of 4 | designators 3xx
Drawn by Abhinav Krishna - EleTect X
DACL > XH-M543 INL > Ahuja SUH-15; amp GND via Q304 (D11)
USART1 D0/D1 shared via 74HC4053, select D4 (ADR 0029)
EleTect X | Designed by Abhinav Krishna
Sheet: /Sound and LoRa/
File: audio.kicad_sch
Title: DFPlayer PRO + Horn + Shared UART

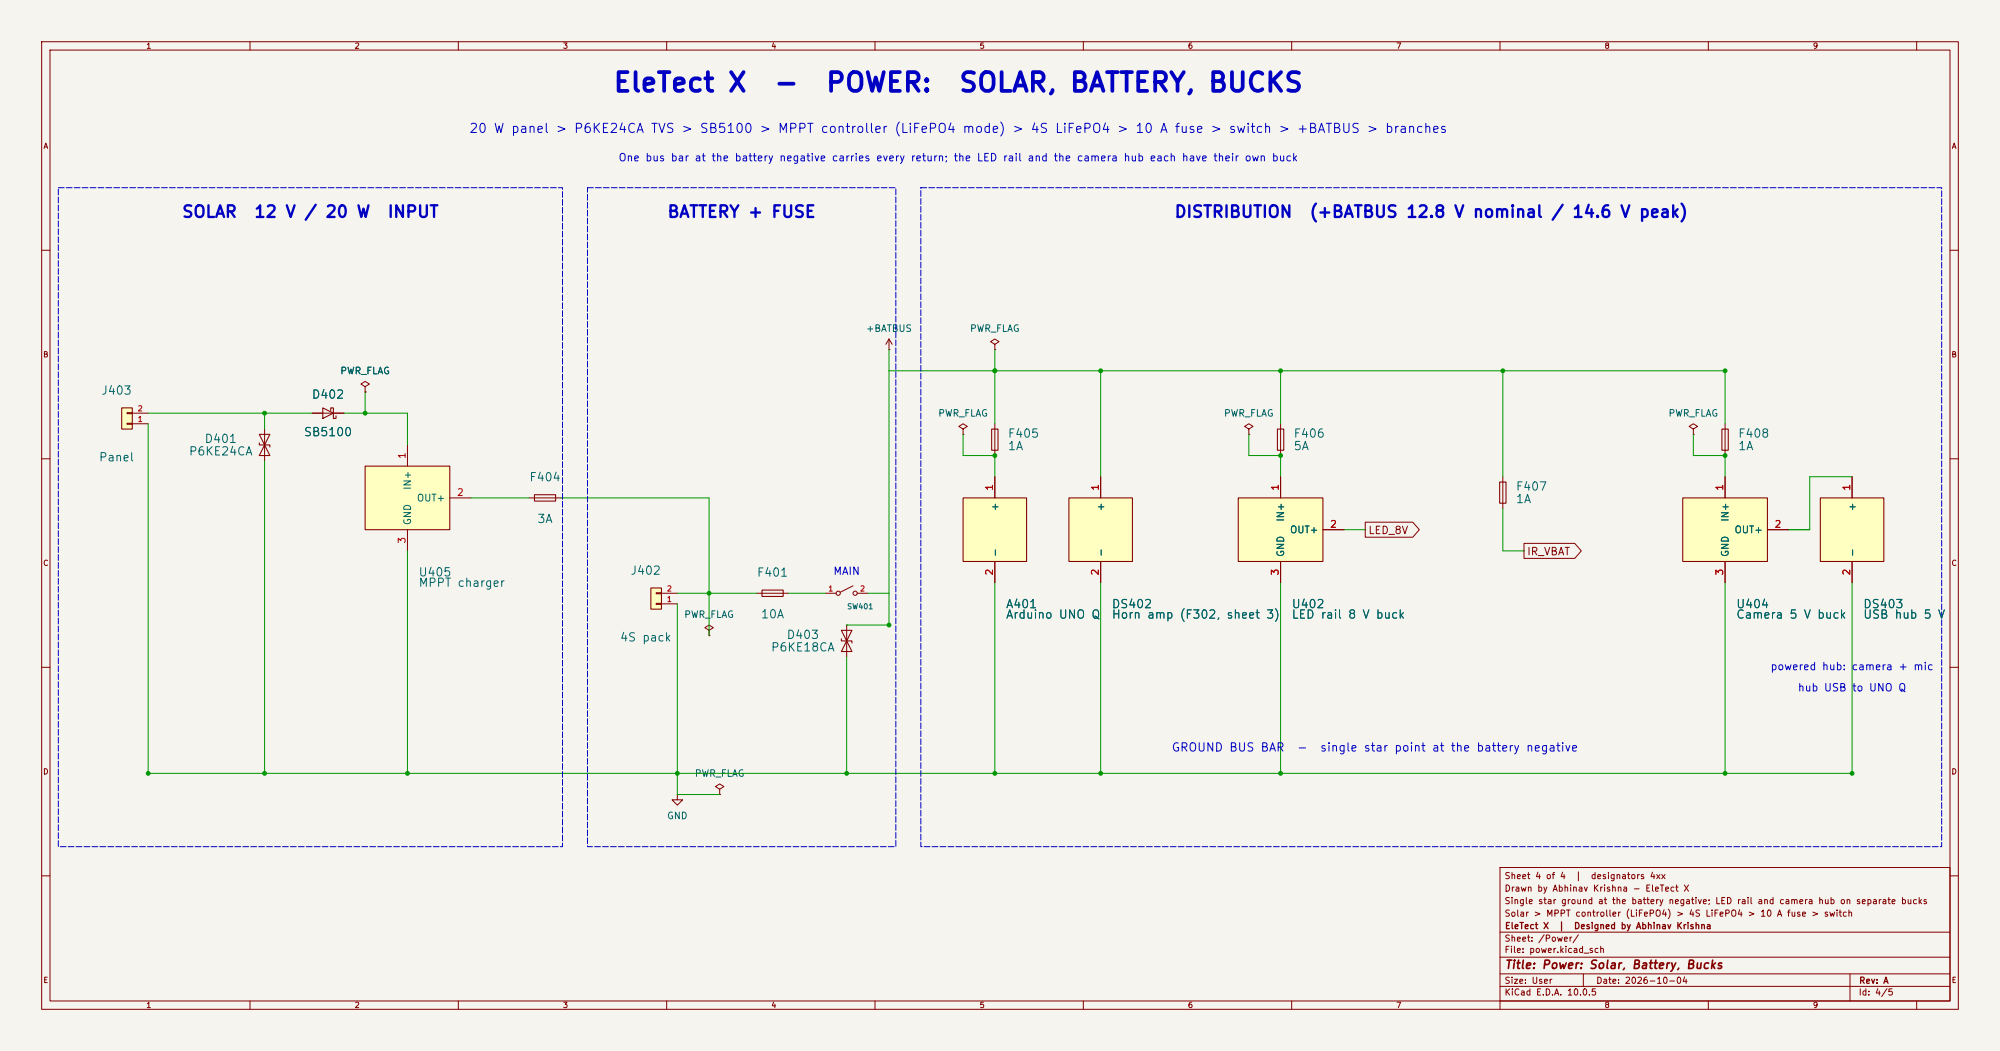
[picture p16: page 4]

EleTect X - POWER: SOLAR, BATTERY, BUCKS

20 W panel > P6KE24CA TVS > SB5100 > MPPT controller (LiFePO4 mode) > 4S LiFePO4 > 10 A fuse > switch > +BATBUS > branches

One bus bar at the battery negative carries every return; the LED rail and the camera hub each have their own buck

LED rail 8 V buck IN+

GROUND BUS BAR - single star point at the battery negative

Sheet 4 of 4 | designators 4xx
Drawn by Abhinav Krishna - EleTect X
Single star ground at the battery negative; LED rail and camera hub on separate bucks
Solar > MPPT controller (LiFePO4) > 4S LiFePO4 > 10 A fuse > switch
EleTect X | Designed by Abhinav Krishna
Sheet: /Power/
File: power.kicad_sch
Title: Power: Solar, Battery, Bucks

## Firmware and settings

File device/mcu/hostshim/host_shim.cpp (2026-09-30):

// HOST BUILD ONLY - see hostshim/Arduino.h.

#include "Arduino.h"

#include <chrono>
#include <cstdio>
#include <cstring>
#include <vector>

#include "Arduino_RouterBridge.h"
#include "Wire.h"

namespace {

constexpr int kMaxPins = 128;
int g_pin_state[kMaxPins] = {};
unsigned long g_millis_offset = 0;
std::vector<hostshim::PinWrite> g_pin_writes;

unsigned long steady_millis() {
  using namespace std::chrono;
  static const auto start = steady_clock::now();
  return static_cast<unsigned long>(
      duration_cast<milliseconds>(steady_clock::now() - start).count());
}

}  // namespace

void pinMode(int, int) {}

void digitalWrite(int pin, int value) {
  if (pin >= 0 && pin < kMaxPins) {
    g_pin_state[pin] = value;
  }
  g_pin_writes.push_back({pin, value, millis()});
}

int digitalRead(int pin) {
  return (pin >= 0 && pin < kMaxPins) ? g_pin_state[pin] : LOW;
}

void analogWrite(int pin, int value) {
  if (pin >= 0 && pin < kMaxPins) {
    g_pin_state[pin] = value;
  }
  g_pin_writes.push_back({pin, value, millis()});
}

int analogRead(int) { return 0; }

unsigned long millis() { return steady_millis() + g_millis_offset; }

unsigned long micros() { return millis() * 1000UL; }

void delay(unsigned long ms) { g_millis_offset += ms; }

void delayMicroseconds(unsigned int us) { g_millis_offset += us / 1000UL; }

namespace hostshim {

int pin_state(int pin) { return digitalRead(pin); }

void advance_millis(unsigned long ms) { g_millis_offset += ms; }

const std::vector<PinWrite> &pin_writes() { return g_pin_writes; }

void reset() {
  std::memset(g_pin_state, 0, sizeof(g_pin_state));
  g_millis_offset = 0;
  g_pin_writes.clear();
}

}  // namespace hostshim

size_t Print::write(const uint8_t *buffer, size_t size) {
  size_t written = 0;
  for (size_t i = 0; i < size; ++i) {
    written += write(buffer[i]);
  }
  return written;
}

size_t Print::print(const char *value) {
  return write(reinterpret_cast<const uint8_t *>(value), std::strlen(value));
}

size_t Print::print(char value) { return write(static_cast<uint8_t>(value)); }

size_t Print::print(int value) { return print(static_cast<long>(value)); }

size_t Print::print(unsigned int value) {
  return print(static_cast<unsigned long>(value));
}

size_t Print::print(long value) {
  char buffer[32];
  std::snprintf(buffer, sizeof(buffer), "%ld", value);
  return print(buffer);
}

size_t Print::print(unsigned long value) {
  char buffer[32];
  std::snprintf(buffer, sizeof(buffer), "%lu", value);
  return print(buffer);
}

size_t Print::print(double value, int digits) {
  char buffer[64];
  std::snprintf(buffer, sizeof(buffer), "%.*f", digits, value);
  return print(buffer);
}

size_t Print::println() { return print("\n"); }

size_t Print::println(const char *value) { return print(value) + println(); }

size_t Print::println(char value) { return print(value) + println(); }

size_t Print::println(int value) { return print(value) + println(); }

size_t Print::println(unsigned int value) { return print(value) + println(); }

size_t Print::println(long value) { return print(value) + println(); }

size_t Print::println(unsigned long value) { return print(value) + println(); }

size_t Print::println(double value, int digits) {
  return print(value, digits) + println();
}

void HardwareSerial::begin(unsigned long baud) {
  baud_ = baud;
  ++begin_count_;
}

void HardwareSerial::end() {}

size_t HardwareSerial::write(uint8_t value) {
  std::fputc(static_cast<int>(value), stdout);
  ++bytes_written_;
  if (tx_len_ + 1 < kTxCapacity) {
    tx_[tx_len_++] = static_cast<char>(value);
    tx_[tx_len_] = '\0';
  }
  return 1;
}

int HardwareSerial::available() {
  return static_cast<int>(rx_head_ - rx_tail_);
}

int HardwareSerial::read() {
  if (rx_tail_ >= rx_head_) {
    return -1;
  }
  return static_cast<unsigned char>(rx_[rx_tail_++ % kRxCapacity]);
}

int HardwareSerial::peek() {
  if (rx_tail_ >= rx_head_) {
    return -1;
  }
  return static_cast<unsigned char>(rx_[rx_tail_ % kRxCapacity]);
}

void HardwareSerial::flush() { std::fflush(stdout); }

void HardwareSerial::host_feed(const char *bytes) {
  for (const char *p = bytes; *p != '\0'; ++p) {
    rx_[rx_head_++ % kRxCapacity] = *p;
  }
}

HardwareSerial Serial;
HardwareSerial Serial1;

void TwoWire::begin() {}

void TwoWire::setClock(uint32_t) {}

void TwoWire::beginTransmission(uint8_t) {}

size_t TwoWire::write(uint8_t) { return 1; }

size_t TwoWire::write(const uint8_t *, size_t size) { return size; }

uint8_t TwoWire::endTransmission() { return 0; }

uint8_t TwoWire::endTransmission(bool) { return 0; }

uint8_t TwoWire::requestFrom(uint8_t, uint8_t quantity) { return quantity; }

int TwoWire::available() { return static_cast<int>(queue_head_ - queue_tail_); }

int TwoWire::read() {
  if (queue_tail_ >= queue_head_) {
    return 0;  // preserves the original always-0 default when nothing fed.
  }
  return queue_[queue_tail_++ % kQueueCapacity];
}

void TwoWire::host_feed_raw(int16_t raw_value) {
  const uint16_t bits = static_cast<uint16_t>(raw_value);
  queue_[queue_head_++ % kQueueCapacity] = static_cast<uint8_t>(bits >> 8);
  queue_[queue_head_++ % kQueueCapacity] = static_cast<uint8_t>(bits & 0xFF);
}

TwoWire Wire;
TwoWire Wire1;
TwoWire Wire2;

void BridgeClass::begin() {}

void BridgeClass::update() {}

BridgeClass Bridge;

#ifndef PIO_UNIT_TESTING
// The firmware's entry points are setup()/loop(), which the Arduino Core
// calls on the board. This main() exists only so pio run -e native proves
// the whole src/ tree links and runs against the stub peripherals without
// crashing - the resulting binary is not a runnable node, does no real
// sensing, and is never flashed (see platformio.ini's header banner).
extern void setup();
extern void loop();

int main() {
  std::printf(
      "eletect-mcu host compile check - firmware entry points are "
      "setup()/loop(), built on the board by App Lab.\n");

  setup();
  constexpr int kSmokeIterations = 600;
  for (int i = 0; i < kSmokeIterations; ++i) {
    loop();
  }

  std::printf("host smoke run completed %d loop() iterations without crashing.\n",
              kSmokeIterations);
  return 0;
}
#endif

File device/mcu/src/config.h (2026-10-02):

// EleTect X - MCU configuration.
//
// Single source of every pin assignment, threshold, gain, cooldown and cap on
// the reflex layer (ENGINEERING_CONVENTIONS.md 2). No magic numbers live in
// logic files; if a number matters, it is named here with the reason it holds
// that value.
//
// Pin assignments come from hardware/references/UNO_Q_PINOUT_REFERENCE.md,
// which is a transcription of Arduino's own ABX00162 pinout PDF. Nothing here
// uses the JMISC or JMEDIA advanced headers: they are 1.8 V board-edge
// connectors that need a carrier board we do not have, so they are physically
// inaccessible.

#ifndef CONFIG_H
#define CONFIG_H

// Per-unit overrides. A node can carry a config_local.h next to this file
// (gitignored, never synced over by scripts/sync-to-board.sh) to override any
// #ifndef-guarded default below without editing the shared tree.
#if defined(__has_include)
#if __has_include("config_local.h")
#include "config_local.h"
#endif
#endif

#include <stdint.h>

// ---------------------------------------------------------------------------
// Geophone front-end - ADS1115 + INA333 bench stand-in, on I2C2
// ---------------------------------------------------------------------------
// The field design samples the INA333 output on the STM32's own ADC through
// LPBAM (ADR 0009). Until that lands, an ADS1115 breakout carries the same
// signal over I2C. Both satisfy one contract, read_seismic_window(), and
// nothing above the driver knows which is underneath
// (ENGINEERING_CONVENTIONS.md 1).
//
// Wiring is plain male-female jumpers to the breakout's 0.1" pin header, not
// the Qwiic connector.
//
// Moved off D20/D21 (I2C2, PB10/PB11) onto A4/A5 (I2C3, PC1/PC0) during the
// horn bring-up: the DFPlayer PRO's AT-command link needs a real hardware
// UART, and usart3 - the only one the board overlay routes to a free header
// pin pair - is pinned to exactly D20/D21 (see DFPLAYER_SERIAL below). I2C3
// was free and is enabled in the same overlay, so the geophone moved rather
// than the DFPlayer link, which has no alternative pin pair. This leaves the
// Qwiic connector's I2C4 (PD12/PD13) free for the BME280/MPU-6050 later, same
// as before.
#define GEOPHONE_I2C_SDA_PIN 18  // PC1, A4, I2C3_SDA
#define GEOPHONE_I2C_SCL_PIN 19  // PC0, A5, I2C3_SCL

// `Wire2` is I2C3. The arduino:zephyr core declares Wire/Wire1/Wire2/... in
// the order listed by the board overlay's
// `zephyr,user { i2cs = <&i2c2>, <&i2c4>, <&i2c3>; }`
// (arduino_uno_q_stm32u585xx.overlay): i2c2 is `Wire`, i2c4 is `Wire1`, i2c3
// is `Wire2`. The overlay's i2c3 node pins `i2c3_scl_pc0`/`i2c3_sda_pc1` -
// exactly A5/A4 - confirming this mapping independently of the pin numbers
// above. Re-run the stomp test after this move and confirm continuous,
// plausible, varying ADS1115 differential readings before trusting anything
// downstream - a wrong bus fails every I2C transaction and produces no
// ring-buffer writes at all, the same signature the pre-move `Wire` mapping
// was confirmed against on 2026-08-14.
#define GEOPHONE_I2C_BUS Wire2

// 0x48 is the ADS1115 address with ADDR tied to GND - the breakout's default.
#define ADS1115_I2C_ADDRESS 0x48

// 400 kHz fast mode: at 250 SPS the bus is idle almost all the time, but the
// faster clock keeps each conversion read short enough that the I2C timeout
// below can stay tight.
#define GEOPHONE_I2C_CLOCK_HZ 400000UL

// ADS1115 register addresses and config-register fields (datasheet 9.6).
#define ADS1115_REG_CONVERSION 0x00
#define ADS1115_REG_CONFIG 0x01

#define ADS1115_CFG_OS_SINGLE 0x8000        // start a single conversion
#define ADS1115_CFG_MUX_DIFF_0_1 0x0000     // differential AIN0 - AIN1
#define ADS1115_CFG_PGA_2048MV 0x0400       // +/-2.048 V full scale
#define ADS1115_CFG_MODE_CONTINUOUS 0x0000  // free-running, not single-shot
#define ADS1115_CFG_DR_250SPS 0x00A0        // 250 samples per second
#define ADS1115_CFG_COMP_DISABLE 0x0003     // comparator off, ALERT/RDY unused

// ---------------------------------------------------------------------------
// Seismic bench-only debug flags - MUST be 0 before any field sync
// ---------------------------------------------------------------------------
// Every flag in this section exists to support a bench characterization
// session (the INA333 REF-bias check, or a later Part C2 sensitivity/
// waveform-capture pass) and has no role in the field-deployed reflex
// behaviour. All four must read 0 before running scripts/sync-to-board.sh
// against a node that is actually going in the ground - device/mcu/README.md
// documents the sync/re-sync procedure that flips them back.
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

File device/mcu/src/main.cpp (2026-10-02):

// setup()/loop() shell wiring the reflex-layer subsystems together.
// Bridge.begin()/Bridge.update() are unconditional, production
// infrastructure as of 2026-08-14 - not gated behind SEISMIC_DEBUG_STREAM_RAW
// the way they used to be. That flag still exists and still gates its own
// bench-only raw-sample relay (geophone.cpp), but Bridge itself is no
// longer bench-only: state_machine.cpp's kSensing case needs a real
// Bridge.notify("report_footfall_event", ...) reachable in every field
// build, or every trigger goes right back to producing a bare console
// timestamp and nothing else (docs/KNOWN_GAPS.md's high-severity
// "Raw seismic trigger data does not reach the MPU" entry, 14 Aug). This is
// the resolution to the decision this file's own comment used to defer -
// "decide how the gate should really read once an actuator RPC goes live" -
// see docs/KNOWN_GAPS.md for the full writeup.
//
// device/mpu/bridge/schema.md's MPU->MCU handlers (drive_horn, drive_led,
// pulse_ir, get_system_state, send_lora_event) have real adapters in
// bridge_handlers.cpp. drive_led and pulse_ir were registered in earlier
// hardware bring-ups; drive_horn joined them with the HOME_TEST_MODE work
// (plan prerequisite 2). send_lora_event is registered with the LoRa build
// (LORA_ENABLED) and is that bring-up's one new function (ADR
// 0029/0030). get_system_state stays deliberately commented out - see
// docs/KNOWN_GAPS.md for why that is deferred to a hardware session, one
// function at a time. Bridge.begin()/Bridge.update()
// running unconditionally does not change that discipline: it makes the
// notify direction reachable, it does not register any provide() handler.

#include "Arduino.h"
#include "Arduino_RouterBridge.h"
#include "bridge_handlers.h"
#include "config.h"
#include "fire_test.h"
#include "geophone.h"
#include "horn.h"
#include "ir.h"
#include "led.h"
#include "mac.h"
#include "state_machine.h"

#if LORA_ENABLED
namespace {

// Heartbeat fields for the status uplink (ADR 0031). No battery ADC is
// fitted yet, so battery goes out as unknown rather than a made-up value.
uplink_status lora_status_now(uint32_t now_ms) {
  uplink_status st{};
  st.flags = (geophone_ok() ? UPLINK_STATUS_FLAG_GEOPHONE_OK : 0) |
             (HOME_TEST_MODE ? UPLINK_STATUS_FLAG_HOME_TEST : 0);
  st.battery_mv = UPLINK_BATTERY_UNKNOWN;
  st.uptime_s = now_ms / 1000UL;
  return st;
}

}  // namespace
#endif

void setup() {
  Serial.begin(CONSOLE_BAUD);

#if HOME_TEST_MODE
  // Loud on purpose - see config.h's HOME_TEST_MODE comment. This line must
  // be the first thing a human sees when opening the console, because the
  // one failure mode this exists to prevent is a board shipped to the field
  // with this flag still on.
  Serial.println("[mode] *** HOME_TEST_MODE - BACKYARD TEST BUILD - NOT FOR FIELD DEPLOYMENT ***");
#else
  Serial.println("[mode] field build (HOME_TEST_MODE=0)");
#endif

  Bridge.begin();

  // get_system_state below is NOT REGISTERED - see
  // bridge_handlers.h and docs/KNOWN_GAPS.md. Each line wires one MPU->MCU
  // function from device/mpu/bridge/schema.md to its adapter in
  // bridge_handlers.cpp.
  // docs/DEVICE_DEVELOPMENT_WORKFLOW.md 3 / ENGINEERING_CONVENTIONS.md 8:
  // registering an additional Bridge.provide() has broken every
  // previously-working one on the same sketch in this project's own
  // history - uncomment exactly ONE line per hardware session, flash,
  // and confirm every already-registered function (including
  // debug_stream_raw_seismic_sample, geophone.cpp) still works before
  // uncommenting the next. Never uncomment more than one at a time, and
  // never as part of a routine sync-to-board.sh push.
  //
  // drive_horn registered with the HOME_TEST_MODE work (plan prerequisite 2),
  // source-level only - this line was uncommented and pushed to the board's
  // on-disk sketch/ tree, but the flash-and-verify step this discipline
  // requires (arduino-app-cli app restart, then confirm drive_led/pulse_ir
  // still work) never ran; it was interrupted before any reflash happened.
  // See HANDOVER.md's 6 Sept section and docs/KNOWN_GAPS.md for the exact
  // stopping point - do not treat this registration as hardware-verified
  // until that gate actually runs. Bridge.begin()/Bridge.update() are
  // unconditional now (see this file's top comment), so that is no longer
  // what gates these four - only the one-at-a-time hardware-verification
  // discipline above does.
  Bridge.provide("drive_horn", bridge_drive_horn);
  Bridge.provide("drive_led", bridge_drive_led);
  Bridge.provide("pulse_ir", bridge_pulse_ir);
  // Bridge.provide("get_system_state", bridge_get_system_state);
#if LORA_ENABLED
  // The LoRa bring-up session's one new function (ADR 0031) - verify
  // drive_horn/drive_led/pulse_ir still answer after flashing it.
  Bridge.provide("send_lora_event", bridge_send_lora_event);
#endif

#if FIRE_TEST_HARNESS
  fire_test_init();
#endif

  geophone_init();
  horn_init();
  led_init();
  ir_init();
#if LORA_ENABLED
  lora_init();
  lora_set_status_source(lora_status_now);
#endif
  state_machine_init();
}

void loop() {
  const uint32_t now_ms = millis();

  Bridge.update();

#if FIRE_TEST_HARNESS
  fire_test_service(now_ms);
#endif

  // Serviced every iteration regardless of reflex state: the geophone ring
  // buffer must keep filling even while the state machine sits in EVENT or
  // COOLDOWN, and the LoRa join state machine must keep advancing
  // independently of sensing.
  geophone_service();
#if LORA_ENABLED
  lora_service(now_ms);
#endif

  state_machine_tick(now_ms);
}

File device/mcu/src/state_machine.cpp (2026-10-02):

#include "state_machine.h"

#include <array>

#include "Arduino.h"
#include "Arduino_RouterBridge.h"
#include "config.h"
#include "footfall_features.h"
#include "geophone.h"
#include "sta_lta.h"

namespace {

reflex_state g_state = reflex_state::kIdle;
uint32_t g_state_entered_ms = 0;

void enter(reflex_state next, uint32_t now_ms) {
  g_state = next;
  g_state_entered_ms = now_ms;
}

// rollover-safe, same pattern as rule_gate_apply().
uint32_t elapsed_since_entry(uint32_t now_ms) { return now_ms - g_state_entered_ms; }

#if SEISMIC_TRIGGER_CONSOLE_LOG
void log_trigger(const sta_lta_result &result, uint32_t now_ms) {
  // Format fixed by device/mcu/README.md's bench stomp-test procedure - keep
  // this line and that doc in sync if either changes. Gated behind
  // SEISMIC_TRIGGER_CONSOLE_LOG (config.h) - see that flag's comment and
  // docs/KNOWN_GAPS.md's 18 Aug entry: this print shares a physical wire
  // with LoRa AT traffic (LORA_SERIAL) and must stay silent in the field.
  Serial.print("[trigger] t=");
  Serial.print(now_ms);
  Serial.print(" sta=");
  Serial.print(result.sta);
  Serial.print(" lta=");
  Serial.print(result.lta);
  Serial.print(" ratio=");
  Serial.print(result.peak_ratio);
  Serial.print(" idx=");
  Serial.println(static_cast<unsigned long>(result.trigger_index));
}
#endif  // SEISMIC_TRIGGER_CONSOLE_LOG

// The real MCU->MPU notify for every trigger (device/mpu/bridge/schema.md:
// report_footfall_event) - the fix for docs/KNOWN_GAPS.md's high-severity
// "raw trigger data does not reach the MPU" gap (14 Aug). probability and
// feature_vector are footfall_features.cpp's honest placeholder derivation
// from this same result/window, not a real TinyML model output yet (see
// that file's own header). Bridge.notify() is fire-and-forget - confirmed
// by reading the real installed Arduino_RouterBridge bridge.h directly
// (docs/KNOWN_GAPS.md, Build-call 5): it takes a write mutex and returns
// after a one-way send, never blocking this loop on an MPU reply.
void notify_footfall_event(const float *window, const sta_lta_result &result, uint32_t now_ms) {
  const float probability = footfall_probability_from_ratio(result.peak_ratio);
  std::array<float, 8> feature_vector{};
  footfall_feature_vector(window, SEISMIC_WINDOW_SAMPLES, result, feature_vector.data());

  Bridge.notify("report_footfall_event", static_cast<uint8_t>(BRIDGE_SCHEMA_VERSION), probability,
                result.peak_ratio, feature_vector);

#if SEISMIC_TRIGGER_CONSOLE_LOG
  // Gated same as log_trigger() above and for the same reason - the real
  // Bridge.notify() call above is untouched, this is only its console echo.
  Serial.print("[notify] t=");
  Serial.print(now_ms);
  Serial.print(" report_footfall_event probability=");
  Serial.print(probability, 4);
  Serial.print(" sta_lta_ratio=");
  Serial.println(result.peak_ratio);
#else
  (void)now_ms;  // now_ms's only consumer is the console echo gated above.
#endif
}

#if SEISMIC_DEBUG_VERBOSE
// Bench-only: sta/lta/ratio on a fixed cadence, independent of whether a
// trigger fires - the [trigger] line above only exists at the moment of a
// crossing, which says nothing about where the ratio sits the rest of the
// time. Rate-limited the same way geophone.cpp's [bias-check] line is.
void log_verbose_ratio(const sta_lta_result &result, uint32_t now_ms) {
  static uint32_t s_last_verbose_print_ms = 0;
  if (now_ms - s_last_verbose_print_ms < SEISMIC_DEBUG_PRINT_INTERVAL_MS) {
    return;
  }
  s_last_verbose_print_ms = now_ms;
  Serial.print("[seismic] t=");
  Serial.print(now_ms);
  Serial.print(" sta=");
  Serial.print(result.sta);
  Serial.print(" lta=");
  Serial.print(result.lta);
  Serial.print(" ratio=");
  Serial.println(result.peak_ratio);
}

// Bench-only, demo visual aid: reruns the same read+detect kSensing's own
// case below already does, purely so this console's ratio line stays alive
// through EVENT/COOLDOWN instead of going dark for the whole dead zone - the
// real reflex logic never sees this call or its result, it only acts on the
// copy computed inside the kSensing case, so the "don't re-trigger mid-event"
// gating this function's caller sits outside of is completely unaffected by
// this existing.
void log_verbose_ratio_now(uint32_t now_ms) {
  float window[SEISMIC_WINDOW_SAMPLES];
  read_seismic_window(window);
  const sta_lta_result result = sta_lta_detect(window, SEISMIC_WINDOW_SAMPLES, STA_SAMPLES,
                                                LTA_SAMPLES, STA_LTA_TRIGGER_RATIO);
  log_verbose_ratio(result, now_ms);
}

// Bench-only: the raw window as CSV volts, for scripts/plot_seismic_window.py
// to render - Part C2's sensitivity/waveform-characterization pass, not the
// REF-bias check. Fires alongside every existing [trigger] line, not on its
// own timer - a trigger is already the interesting moment to keep the trace
// for.
void log_window_csv(const float *window, size_t n, uint32_t now_ms) {
  Serial.print("[window] t=");
  Serial.print(now_ms);
  Serial.print(" n=");
  Serial.print(static_cast<unsigned long>(n));
  Serial.print(" rate_hz=");
  Serial.print(SEISMIC_SAMPLE_RATE_HZ);
  Serial.println(" unit=volts");
  for (size_t i = 0; i < n; ++i) {
    Serial.print(window[i], 6);
    if (i + 1 < n) {
      Serial.print(",");
    }
  }
  Serial.println();
}
#endif  // SEISMIC_DEBUG_VERBOSE

}  // namespace

void state_machine_init() { enter(reflex_state::kIdle, millis()); }
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

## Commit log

2026-07-09 fix: correct stale directory paths after device/mcu+mpu and web rename
    CI workflow, .gitignore, README, and the project blueprint still
    referenced the pre-restructure layout (firmware/stm32, linux/, ai/,
    cloud/, dashboard/). Bring them in line with docs/STRUCTURE.md so
    ignore rules and CI actually match the tree.
2026-07-09 feat(web): build home page
    Port the landing page from the design export: hero, crisis stats,
    how-it-works steps, image interlude, capability comparison table,
    solutions preview grid, awards band, and closing CTA.
    Swapped in verified Asian elephant and Western Ghats imagery
    throughout and pointed the CTA links at the existing /dashboard
    route since auth pages aren't built yet.
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2026-07-09 fix(web): use canonical Tailwind classes over arbitrary values
    Replace bracket values that exactly match design tokens (opacity
    fractions, spacing multiples, viewport height, background-position)
    with their canonical utility equivalents.
2026-07-09 fix(web): rename v4-renamed Tailwind utilities and canonical opacity
    bg-gradient-to-r and flex-shrink-0 are pre-v4 utility names; use
    bg-linear-to-r and shrink-0. Also express 1.5% opacity as a decimal
    modifier instead of an arbitrary bracket value.
2026-07-09 test(web): add phase 2 build-vs-design QA screenshot comparison
    Add a Playwright script that captures every public page at desktop
    (1440x900) and mobile (390x844) widths, for both the built React app
    and the matching screen in the design reference prototype, so the two
    can be compared side by side. Screenshots are saved in pairs under
    docs/qa/phase2/ and double as build evidence for the project writeup.
    The design reference is a hash-routed single page app, so each page is
    captured by navigating to its route (e.g. #/technology) against a
    locally served copy rather than opening the file directly, since the
    prototype's runtime does not render correctly under file:// URLs.
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2026-07-10 fix(web): qualify search_path and use SECURITY DEFINER in RLS helpers
    is_staff() and is_admin() are called from profiles' own RLS policies. Running
    them as the invoking role re-triggered profiles' RLS, which called them again,
    recursing until Postgres hit a stack-depth error that PostgREST surfaced as a
    bare 500. Mark them SECURITY DEFINER so the internal profile lookup bypasses
    RLS; they only ever return a boolean, so no row data leaks.
    Also pin search_path=public and schema-qualify table names in these helpers,
    handle_new_user(), and the officer approve/reject functions. handle_new_user()
    fires as supabase_auth_admin, whose search_path excludes public, so unqualified
    names failed with rel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
2026-07-10 feat(web): wire replay, corridor, and learning dashboard routes
    Replaces the placeholder panels for the replay, network, and learning tabs with
    the live views, keeping the existing officer/admin role gate.
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2026-07-10 feat(web): render every dashboard map on real Leaflet tiles
    Swap the basemap from CARTO dark_all to CARTO Voyager (labels_under). Voyager
    carries road hierarchy, place names and natural colours, so an officer can see
    which road a herd is being steered away from and which settlement is downstream.
    Free, OSM-sourced, no API key. labels_under paints place labels beneath the
    overlay panes, keeping pins, the corridor line and the herd marker unobscured.
    Replay and Corridor drop the abstract SVG sector map and reuse LiveMap, which
    grows optional overlays: pulsing active nodes, a dashed corridor polyline, and a
    herd marker. Leaflet positions a marker icon with a transform, so a CSS
    transition on i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
2026-07-10 test(web): add map realism QA screenshots
    Captures Overview, Replay and Corridor on desktop and mobile against the Voyager
    basemap, plus frame sequences for the Replay scrub and the Corridor handoff. Each
    frame logs the herd marker's computed transform, so the sequences prove the
    marker interpolates between nodes rather than snapping onto them.
2026-07-10 fix(web): frame incident bounds against the measured container size
    Leaflet caches the container size at L.map() time and getBoundsZoom()
    measures against that cache rather than the DOM. The map mounts before the
    surrounding header has settled, so fitBounds ran against a stale size and
    picked a zoom one step off — Replay settled a level too far out, Corridor a
    level too far in, which pushed S7-11's anchor outside a 390px viewport and
    clipped its label. Same nodes, same padding, different framing per view.
    Call invalidateSize() before fitting, and re-fit from a ResizeObserver so the
    frame never outlives the size it was computed against. Pad for the drawn pin
    rather than its anchor: the id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
2026-07-10 feat(backend): add demo scenario RPCs and node state snapshot
    Demo Mode needs to make the full system act for a reviewer with no live
    hardware present, without inventing a client-side animation: every
    scenario step writes real, tagged rows through a SECURITY DEFINER RPC,
    so it flows through the true realtime pipeline the same way a live
    node's telemetry would.
    run_demo_scenario() covers six scenarios behind an is_staff() guard and
    a fixed whitelist, each writing events/health/maintenance rows tagged
    so reset_demo_data() can find and remove them again, and restoring any
    mutated node from a new demo_node_snapshot table rather than assuming
    an "online" default - a demo run must not corrupt rea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
2026-07-10 fix(backend): never fan out alerts for demo-tagged events
    send-alert is wired to a Database Webhook on events INSERT and fans
    SMS out to every officer and opted-in resident within 3 km of a
    high-priority event. Demo Mode writes real event rows through the same
    path, so without this guard a scenario run - a reviewer clicking through
    a demo, or routine testing - would page real Kothamangalam residents.
    The media_url === 'demo' check is now the first statement the handler
    executes, before the payload is inspected for anything else, and fails
    closed on an unreadable payload. This sits alongside, not instead of,
    demo events always being written priority='normal': two independent
    barriers on two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
2026-07-28 feat(mcu): geophone window over ADS1115 stand-in
    read_seismic_window() satisfies both halves of the schema contract
    by snapshotting a ring buffer that geophone_service() fills
    incrementally every loop() iteration, rather than blocking for a
    full 512-sample window (2.05s at 250 SPS). A failed I2C transaction
    or a stale buffer returns a zero-filled window and clears
    geophone_ok(), never a null/exception.
    ADS1115 register access is hand-rolled rather than pulled in as a
    library dependency.
    [geophone.cpp]
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2026-07-28 feat(mcu): horn, led and ir drivers
    Thin shells over rule_gate_apply() - each calls the shared clamp
    core, drives GPIO for the resolved duration, and returns the ack.
    led/ir keep independent per-channel cooldown counters so one
    channel firing never gates another.
    horn.cpp is the sole owner of AUDIO_TRIGGER_PIN and
    HORN_AMP_ENABLE_PIN. Fire sequence: amp held in shutdown -> pulse
    the DFPlayer trigger -> wait HORN_AMP_ENABLE_DELAY_MS for it to
    seek -> bring the amp out of shutdown, so neither the trigger
    transient nor the amp's own un-mute reaches the horn as a pop.
    Teardown reverses the order for the same reason. The delay value
    is an unmeasured placeholder (docs/KNOWN_GAPS.md).
    [horn.cpp, led.cpp, led.h]
2026-07-28 feat(mcu): lora e5 otaa join
    Non-blocking OTAA join state machine on USART1 for the Grove
    LoRa-E5 - one command per lora_service() call, per-command timeout,
    bounded retry with backoff, so a slow or unresponsive module never
    stalls the reflex loop. IN865 only (ADR 0002); AppKey is read from
    the gitignored secrets.h and never printed back over the console.
    AT command syntax is cited against Seeed's own Grove LoRa-E5 AT
    Command Specification but has not been checked line-by-line against
    it - every unverified token is marked inline and logged in
    docs/KNOWN_GAPS.md, not left looking authoritative.
    [mac.cpp]
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2026-07-29 feat(mpu): bridge rpc contract stubs
    One stub per row of bridge/schema.md's two function tables -
    signatures and docstrings only, raise NotImplementedError bodies, no
    Bridge.provide()/Bridge.call() wiring. DEVICE_DEVELOPMENT_WORKFLOW.md
    3 documents a live, reproducible bug where registering an extra
    Bridge.provide() function broke every previously-working function on
    the same sketch; the discipline that earns is registering one
    function at a time on real hardware, not wiring a batch of seven from
    a host build with no board attached. The MCU side observes the same
    caution.
    report_footfall_event, report_acoustic_event, and report_system_status
    are notify targets (MCU never blocks on them); dr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
    [rpc.py]
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2026-07-29 feat(mpu): hello-world bridge ping bench app
    device/mpu/bench/ping/ is a complete, disposable App Lab app,
    deliberately separate from the real EleTect-X app and from
    bridge/rpc.py's schema stubs: exactly one Bridge function
    (sketch/main.cpp calls Bridge.call("ping", token) every 2s,
    python/main.py answers with Bridge.provide("ping", ...)), nothing
    schema-shaped.
    Rung 0 proved a Bridge round trip Python -> MCU only (stock Blink LED).
    This exercises the reverse, MCU -> Python, which every MCU->MPU notify
    in the schema needs and which nothing has demonstrated on this board
    yet. Uses call rather than notify on purpose - a verifiable pong reply
    is a better bench test than a fire-and-forget notif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
    [main.cpp]
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2026-07-29 fix(mpu): drop py311-only StrEnum from bridge/rpc.py
    AcousticClass used enum.StrEnum (3.11+), an unintended hard
    dependency - pytest couldn't even collect bridge/rpc.py under the
    dev host's default python (3.10). Swaps to `class AcousticClass(str,
    Enum)`, identical runtime behavior, no version floor above 3.10.
    Also drops pyproject.toml's ruff target-version from py311 to py310
    to match: leaving it at py311 made ruff's UP042 rule push the class
    straight back toward StrEnum. py310 syntax runs fine on the board's
    assumed Python 3.11 too, so this costs nothing there.
    [rpc.py]
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2026-07-30 feat(mcu): bench-only seismic debug flags and ADS1115 MUX override
    Add GEOPHONE_DEBUG_SINGLE_ENDED_AIN0, SEISMIC_DEBUG_VERBOSE, and
    SEISMIC_DEBUG_PRINT_INTERVAL_MS as a clearly-marked bench-only section,
    each defaulting to 0. The first swaps ADS1115_CONFIG_WORD's MUX field to
    single-ended AIN0-vs-GND via a new ADS1115_CFG_MUX_ACTIVE indirection,
    without touching the existing ADS1115_CFG_MUX_DIFF_0_1 constant, so the
    INA333 REF-bias check can read VOUT against board GND instead of
    differentially against UREF.
    [config.h]
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2026-07-30 fix(mcu): update include paths and build config for flat sketch layout
    Every quoted #include in src/ now points at a sibling file instead of
    a subfolder (actuators/rule_gate.h -> rule_gate.h, etc). platformio.ini
    drops the now-gone include/ dir from its search path, .gitignore and
    sync-to-board.sh follow secrets.h to its new src/ location, and
    device/mpu's config test follows config.h the same way.
    [horn.cpp, led.cpp, main.cpp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]
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2026-08-15 feat(mcu): wire report_footfall_event notify into the reflex loop
    state_machine.cpp's kSensing case now calls Bridge.notify("report_footfall_event",
    ...) on every STA/LTA trigger, carrying the real sta_lta_ratio and an 8-feature
    per-window vector (footfall_features.cpp) plus a saturating placeholder
    probability derived from peak_ratio (config.h's FOOTFALL_PROBABILITY_SATURATION_C) -
    ml/seismic has no trained model yet, so this is an honest stand-in, not a real
    confidence score. The probability formula is x^2/(x^2+c^2) rather than the
    originally-tried exponential form, which failed to link on the real board
    (libm_nano.a's expf needs __errno, which the field build's -nostdlib toolchain
    doesn't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
    [config.h, host_shim.cpp, main.cpp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]
2026-08-15 perf(mcu): gate kSensing STA/LTA re-run on new samples, fix stale-window constant, drop dead detrigger ratio
    state_machine_tick()'s kSensing case re-ran the full read_seismic_window()
    + sta_lta_detect() slide (~72k float ops) on every loop() iteration even
    when geophone_service() had not accepted a new sample since the last
    check. Add geophone_sample_count(), a monotonically increasing count of
    accepted samples, and gate kSensing on it advancing. geophone_service()
    now also runs its own proactive staleness check every call so geophone_ok()
    stays current in real time even though kSensing calls it less often.
    GEOPHONE_WINDOW_STALE_MS updated from 3072 to 3384 to match its own
    documented formu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
    [config.h, geophone.cpp, state_machine.cpp]
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2026-08-17 fix(mcu): correct LoRa-E5 AT-command sequence against verified manual
    Checked every AT command and expected response in the OTAA join state
    machine against the Seeed LoRa-E5 AT Command Specification V1.0 text
    layer (previously written from memory of typical AT-modem behavior).
    Key correction: the join-success string is "+JOIN: Done", not "Network
    joined" - the latter does not appear anywhere in the manual and would
    have left the join state machine unable to ever observe success.
    Also drops the unverified explicit channel-mask step (AT+CH is
    US915/AU915/CN470-only per manual sec 3.9.1, not needed for IN865) and
    fixes the several "OK"-only response gates that don't match the
    command-specific r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
    [led.h, mac.cpp]
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2026-08-17 build(hardware): revise power budget, split horn enclosure, add first-pass CAD
    Power system revised 13-14 Aug against a real daily energy budget
    (eletect-x-power-budget.xlsx) and real Kerala monsoon-season solar
    irradiance: dropped the "smart" LiFePO4 solar controller category
    entirely after every purpose-built unit checked failed real
    verification, replaced with a manually-set XL4015 buck plus the
    battery's own BMS as the load-bearing safety component. Battery,
    panel, fuse, and passives sourcing all updated with real ordered/
    in-hand status and product links.
    enclosure-design-concept.md updated for ADR 0011's horn/main-enclosure
    split, plus a first-pass CadQuery block-out (main_enclosure_s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
    [eletect-x-power-budget.xlsx, main_enclosure_assembly.step, main_enclosure_shell.step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]
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2026-08-17 fix(mcu): point LORA_SERIAL at Serial, not Serial1
    Serial1 is bound to lpuart1, the internal Bridge MCU<->MPU link, not
    the physical D0/D1 UART the Grove LoRa-E5 is wired to. Confirmed by
    reading the board's own installed zephyr core devicetree overlay
    directly and cross-checking against journalctl -u arduino-router,
    which opens /dev/ttyHS1 (lpuart1's Linux node) for its own link.
    Live join test on the corrected wire got no response from the module
    across 6 AT-probe retries, so the join sequence itself is still
    unproven on hardware - documented in KNOWN_GAPS.md along with two
    candidate causes and the newly surfaced console/LoRa wire-sharing
    conflict. Wiring status stays at in-progress, not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
    [config.h]
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2026-08-20 fix(mcu): gate state_machine console prints off shared LoRa wire
    state_machine.cpp's [trigger]/[notify] prints fired unconditionally
    on every geophone trigger and went out over the same physical wire
    LORA_SERIAL now uses for the E5 (docs/KNOWN_GAPS.md, 18 Aug), so a
    footfall mid-join or mid-uplink would land on the module's RX pin as
    noise. Add SEISMIC_TRIGGER_CONSOLE_LOG (config.h, default 0, same
    discipline as SEISMIC_DEBUG_STREAM_RAW/FIRE_TEST_HARNESS) and gate
    both prints behind it; the real Bridge.notify report_footfall_event
    call is untouched, only the redundant console echo is silenced.
    Went with a flag rather than rerouting through Bridge.notify() the
    way SEISMIC_DEBUG_STREAM_RAW do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
    [config.h, host_shim.cpp, state_machine.cpp]
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2026-08-22 fix(horn): correct AUDIO_TRIGGER_PIN polarity for DFPlayer PRO ADKEY circuit
    The DFPlayer PRO's DF1101S chip pulls its KEY/ADKEY input up to its own IO
    rail (idle high) and reads a direct short to ground as a key press. horn.cpp
    had this backwards: it idled the pin low (holding K1 pressed continuously
    from boot) and pulsed it high to "trigger" (releasing a held button rather
    than pressing one), producing no correct trigger on real hardware.
    Flip idle/pulse polarity in horn_init() and horn_fire_sequence(), document
    the active-low/pull-up-idle-high behavior at both call sites, and add
    test_horn covering the idle-high state after init and after a completed
    fire - the gap that let the original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
    [config.h, horn.cpp]
2026-08-22 feat(mpu,mcu): scaffold LoRa direct-alert transport for gunshot path
    Add the send_lora_alert Bridge function (schema.md, rpc.py, MCU-side
    bridge_handlers.h/.cpp) that ADR 0007 5's gunshot branch now calls for
    real outside safe_mode, replacing the log-only placeholder. No real
    transport exists yet - the MCU handler always acks false and every new
    Bridge.provide() registration (both sides) stays commented out, same
    one-at-a-time discipline as drive_horn/drive_led/pulse_ir/
    get_system_state. Blocked on the Grove LoRa-E5 module not answering AT
    probes (KNOWN_GAPS.md, 18 Aug), not on missing code.
    Host-tested: pytest 224/224 (device/mpu), pio test -e native 49/49
    (device/mcu), including the new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
    [bridge_handlers.cpp, main.cpp, rpc.py]
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2026-10-01 docs(mcu): correct four comments that describe behaviour the code does not have
    Found while tracing the real worst-case duration of a horn fire for the
    deterrence-before-uplink ordering work. None of these change a constant or an
    executable line; the one deletion is of two constants nothing reads.
    The three-roar replay was specified on 7 Sept and never implemented.
    horn_fire_sequence() plays the track once and has no repeat loop, so
    HORN_REPEAT_COUNT and HORN_REPEAT_GAP_MS had no reader anywhere in the tree.
    They are deleted and the comment now records the field finding as a standing,
    unaddressed requirement rather than as shipped behaviour - the 7 Sept
    observation that one 3 s burst did no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
    [config.h, horn.cpp]
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2026-10-02 docs: point the MCU config references at the file that exists
    Nine places across eight files cite device/mcu/include/config.h. There is no
    include/ directory in device/mcu and there never has been - the header is at
    device/mcu/src/config.h. Among them is the first line of the pinout reference,
    which calls that path the source of truth for every pin assignment, so the one
    document a person consults before wiring a board sends them to nothing.
    This commit corrects the three files that were otherwise clean. The remaining
    five are already modified in the working tree by unrelated in-flight work and
    carry the same correction there, to land with it.
    [rpc.py]
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2026-10-02 fix(mpu): realign the Bridge schema version with the MCU and patch fixint
    The committed MCU has sent BRIDGE_SCHEMA_VERSION 128 since the 9 Sept bench
    session; the MPU was still sending 4. Every actuator RPC from a clean
    checkout is therefore rejected by the MCU's version guard before it reaches
    a handler, so nothing fires - horn, LED and IR alike. This closes that.
    Why 128 and not 5: the vendored on-device MsgPack 0.4.2 mis-decodes any
    unsigned integer small enough to encode as MessagePack positive fixint
    (0-127, one byte), rejecting the call as MALFORMED_CALL_ERR even though the
    value is correct. Bench-verified by holding every other field fixed and
    varying only this one - 200 unpacked, 0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
    [wire_compat.py]
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2026-10-02 feat(hardware): track the geophone front-end and LED/IR schematics
    Two KiCad schematics that two tracked documents already point at - PIN_MAP's
    PC1 row cites geophone-frontend.kicad_sch as where the geophone I2C is routed,
    and the LED/IR sheet is cited for the actuator wiring. Both references have been
    dangling.
    The ERC reports go with them, errors included. They are the usual
    power_pin_not_driven set that a schematic with no PWR_FLAG symbols produces, and
    these sheets have no board layout behind them yet, so the reports are a record
    of a known state rather than a clean bill. Committing a passing report and
    omitting a failing one is how a checklist stops meaning anything.
    Local artifacts s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
    [geophone-frontend.kicad_sch, led-ir-actuators.kicad_sch]
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2026-10-02 docs(vision): record the Fox-class work and the 128px resolution result
    Six weeks of entries that existed only as run logs. The useful content is the
    negative results: Fox was sourced and retrained four times and was not promoted
    on the first three, and the reasons are specific enough to act on.
    Pass 1-3: Fox recall kept falling as the share of real night/IR imagery in the
    class grew, which is the opposite of the intended direction and the signal that
    the external sources were not representative of what the node actually sees. An
    `expect_images` reconciliation bug was found and fixed in pass 3 - counts were
    being checked against the pre-augmentation project metadata, so a short export
    read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
    [board-pull-20260923-review-triage.csv, board-pull-20260924-27-review-triage.csv]
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2026-10-02 docs: rewrite working-session register out of device and script comments
    Comments across device/mcu, device/mpu and scripts/ were written in the
    register of the working session that produced them - "this session",
    "tonight's test", "later build calls", "the user", "the project owner". None
    of that survives contact with a reader who was not there: "tonight" has no
    referent in a file read six months later, and "the user" names nobody in a
    repository a forest division will operate.
    Each one is replaced with the engineering fact it stood for - the dated field
    test, the mode, the operator - rather than deleted, because in almost every
    case the circumstance was the reason the constant has the val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
    [config.h, main.cpp, state_machine.cpp]
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2026-10-03 feat(mcu): report how long an event waited before it was sent
    The server has no way to know when an event happened. It stamps a row with
    its own receive time, so a frame delayed by a horn fire, two send retries or
    a join backoff is filed as having just happened, and a half-hour-old alert
    sorts above a fresh one with nothing to tell them apart.
    The node has no RTC and no synchronised clock, so it cannot report an
    absolute time - but elapsed time needs no synchronisation, and elapsed time
    is exactly what the server is missing. The event frame grows from 10 to 12
    bytes: 10-11 carry age_s, u16 big-endian, 0xFFFF when the node cannot say.
    The server dates the event at its receive time less age_s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
    [mac.cpp]
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2026-10-04 docs(hardware): replace schematics with four-sheet eletect_x KiCad project
    Geophone, LED/IR, sound/LoRa and power sheets under one hierarchical
    project with a shared UNO Q label, plus the PDF export and ERC report.
    Removes the earlier standalone geophone and LED/IR schematics.
    [audio.kicad_sch, eletect_x.kicad_sch, geophone-frontend.kicad_sch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]
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
